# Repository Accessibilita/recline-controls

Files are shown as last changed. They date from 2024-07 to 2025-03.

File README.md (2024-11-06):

# Open Source Wheel Chair Recline Control System
## Hardware project for open source wheel chair recline control electronics

The Recline control system allows the wheel chair user to adjust the recline position of their chair at their leisrure. Its a complete electrical controls system with with safety in mind. The system is split across two piece of electrical hardware design as two separated printed circuit boards. The First board functions as the controller and human machine interface, the second board functions as an intelligent controller for the actuators, solenoids, and air compressor related to controlling the chair recline postion and the chair's pneumatic suspension.The human machine interface board is called the Reline Control board, and the actuator controller is called the Recline Actuator Control board. 

The system is split across two printed circuit boards for a couple of reasons, the signals from the switches and buttons are low voltage signals, running those signals through long wires would cause problems witha accurately reading the position of the rocker switches and buttons due to voltage drop, the LEDs in the 7 segment display have a low forward voltage and need to be close to the driving source for them to work, if the wire is too long voltage drop would prevent the LEDs from turning on, the other reason is the actuators and solenoids are high voltage signals and need to be mounted close to the control board. The Recline Control Board will be mounted on the arm rest of the users's dominant hand, it runs off 24V power and sends commands to the Recline Actuator control board via RS485 serial communication. The Recline Actuator Control board will be mounted in a secure location most likely at the botton of the chair between the chair and it the rolling chassis, it will be fed 24V power and connect to the Recline Control Baord via RS485. 

## Block Diagram of Entire System
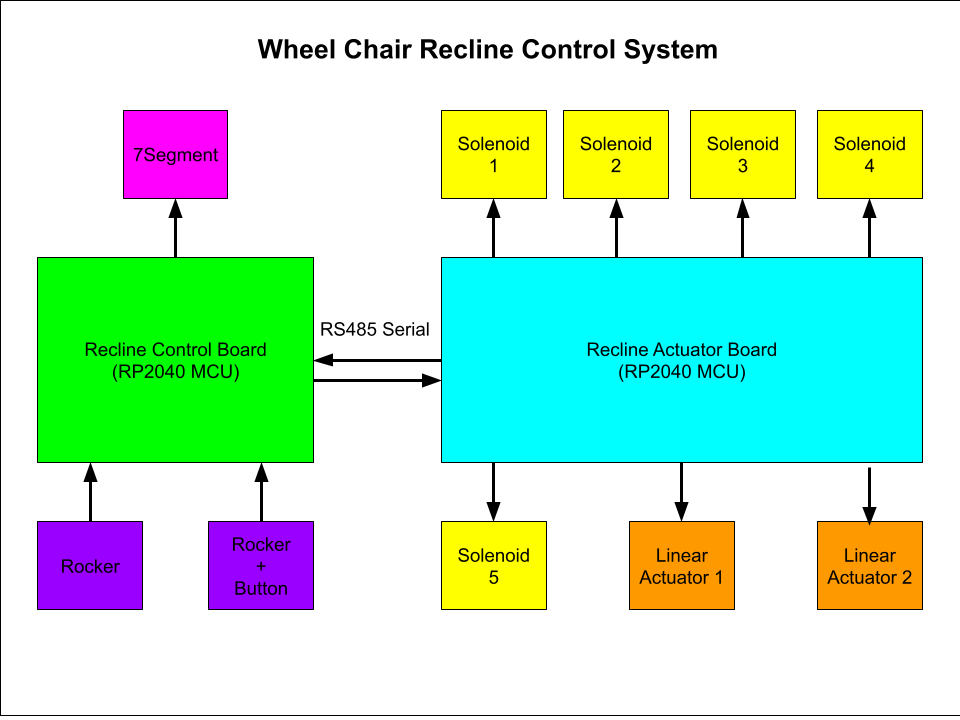
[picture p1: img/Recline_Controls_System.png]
System Diagram


# Board Specs and 3D Renders:

## Recline Control Board 

The other board, called the Recline Control board, functions as the user interface and control center. Here's what it does:

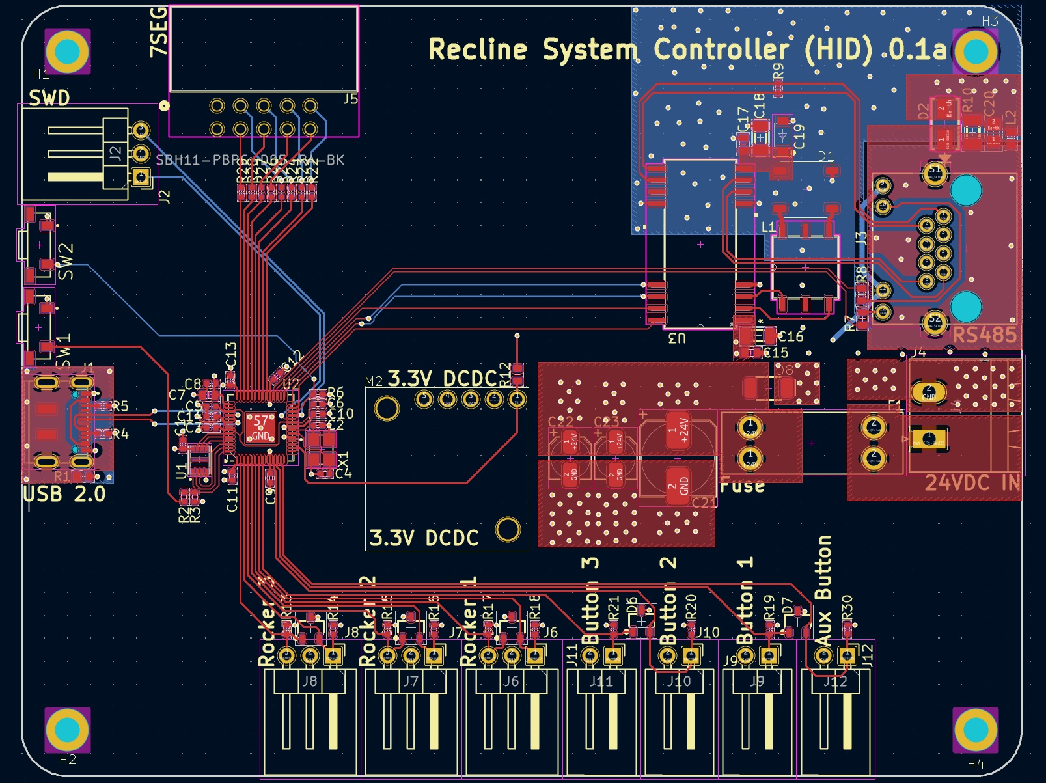
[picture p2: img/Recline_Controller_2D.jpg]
Recline Control Board 2D Render


  Acts as the Human-Machine Interface (HMI): This board is where the user interacts with the system, using buttons and rocker switches to adjust the recline position of the chair.
  Processes Low-Voltage Signals: It handles low-voltage signals from the user input controls, like switches and buttons, to avoid issues with voltage drop.
  Displays Information: Includes a 7-segment display to show information, such as the recline position, which requires low forward voltage and needs to be close to the control board to avoid voltage drops.
  Sends Commands via RS485: It sends user commands to the Recline Actuator Control board through RS485 serial communication, which then controls the actuators and other high-voltage components.
  Mounted for User Access: It’s mounted on the armrest of the user's dominant hand, providing easy access for adjustments.

In essence, the Recline Control board is the user-friendly interface, interpreting user input and communicating these commands to the Recline Actuator Control board via RS485 to execute the recline and suspension adjustments.

### Specs:
- RP2040 Microcontroller
- Pololu DCDC Switching Regulator Modules for 3.3V and 5V Power
- Locking Molex connector for Rocker Switches and Buttons
- RJ45 Connector for RS485 Signals 
- Phoenix Contact high voltage connector for Power Input
- Automotive Blade Fuse Carrier and Crowbar Circuit Protection

### 3D Renders:

Top
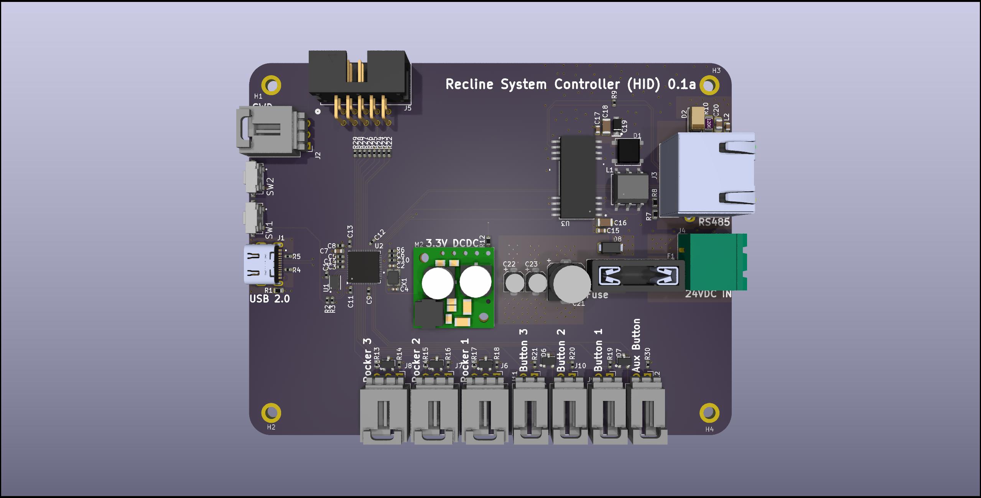
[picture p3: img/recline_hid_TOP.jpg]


Bottom
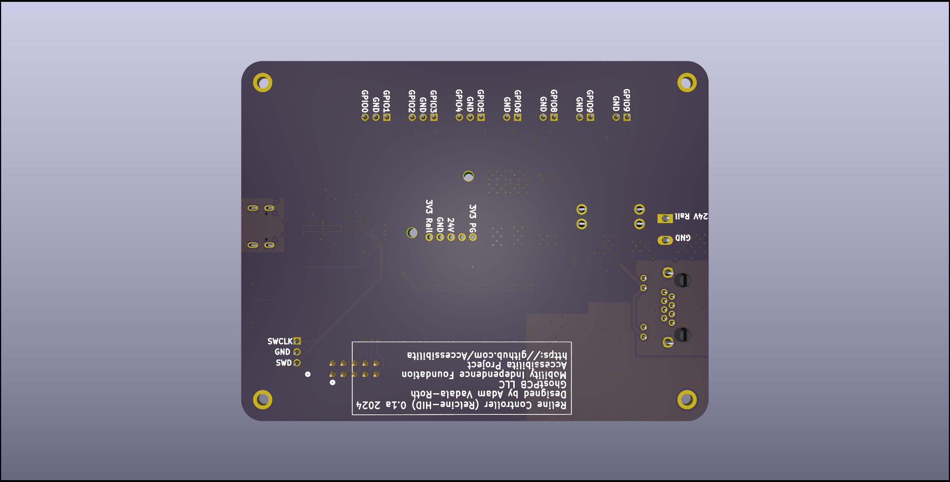
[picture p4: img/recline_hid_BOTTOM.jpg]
Bottom


ISO
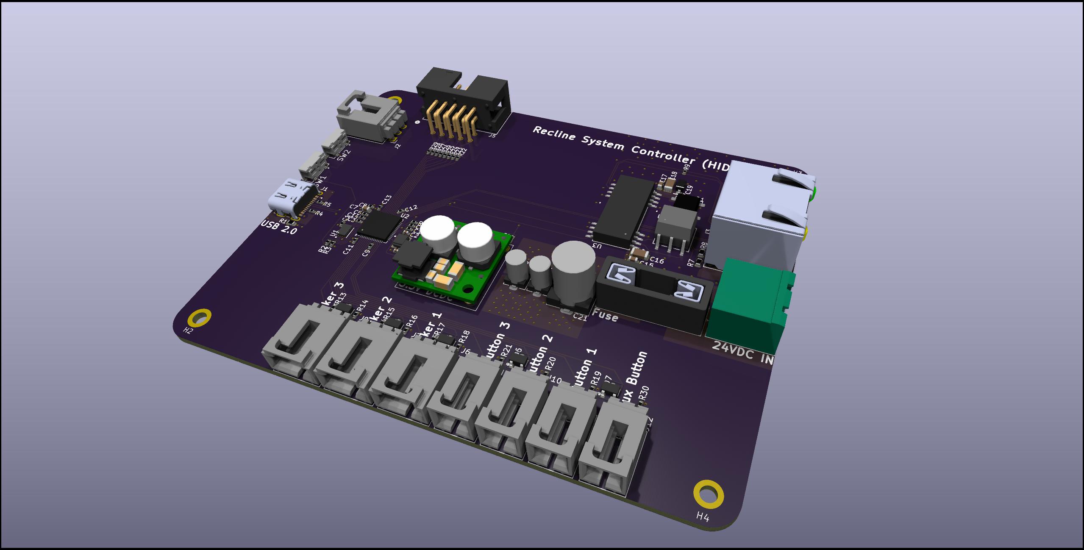
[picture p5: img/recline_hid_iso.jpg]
ISO


Side A
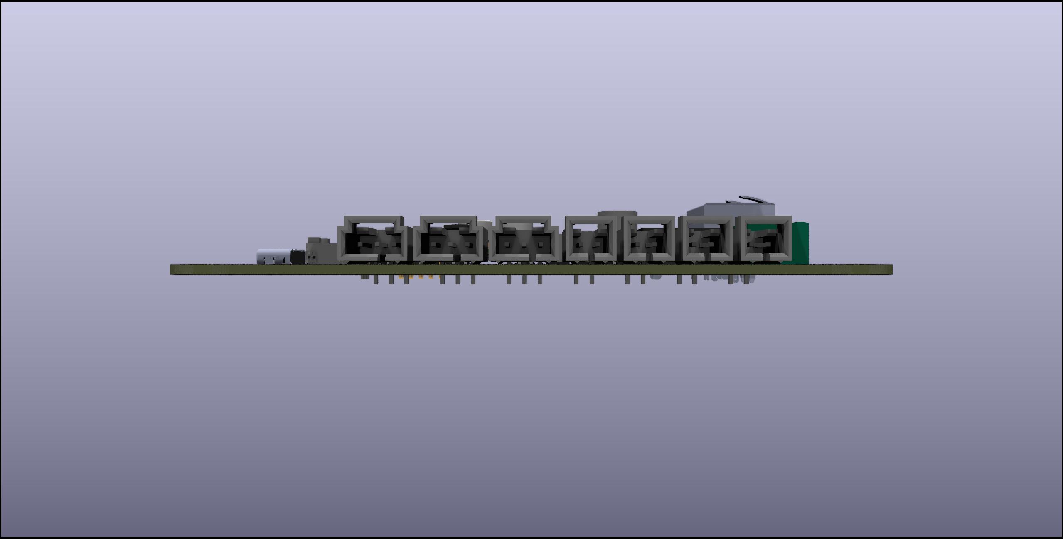
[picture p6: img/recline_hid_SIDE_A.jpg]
Side A


Side B
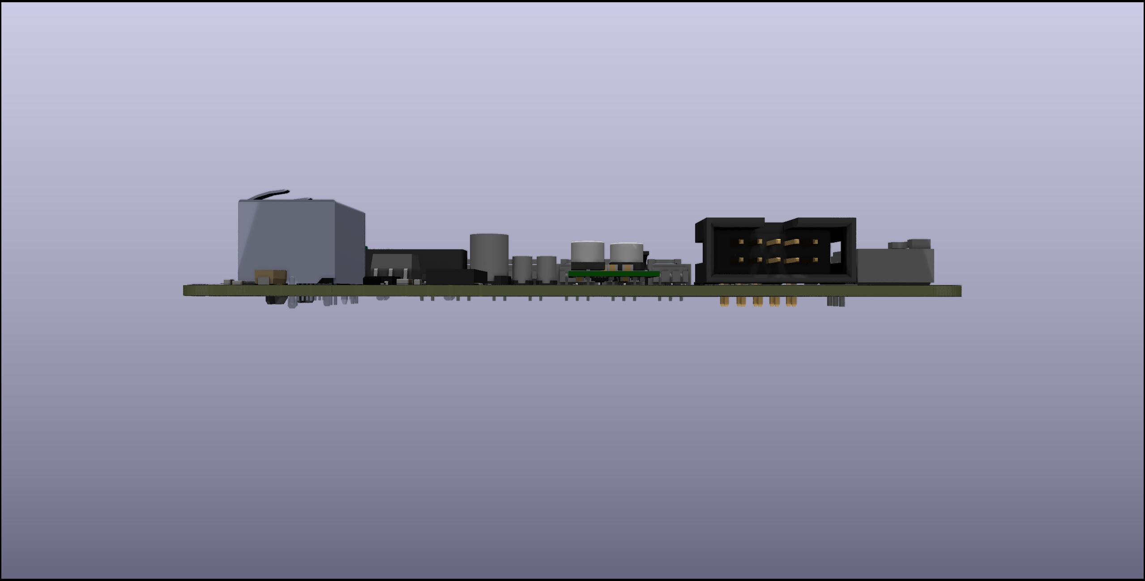
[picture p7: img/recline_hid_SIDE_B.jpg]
Side B


Side C
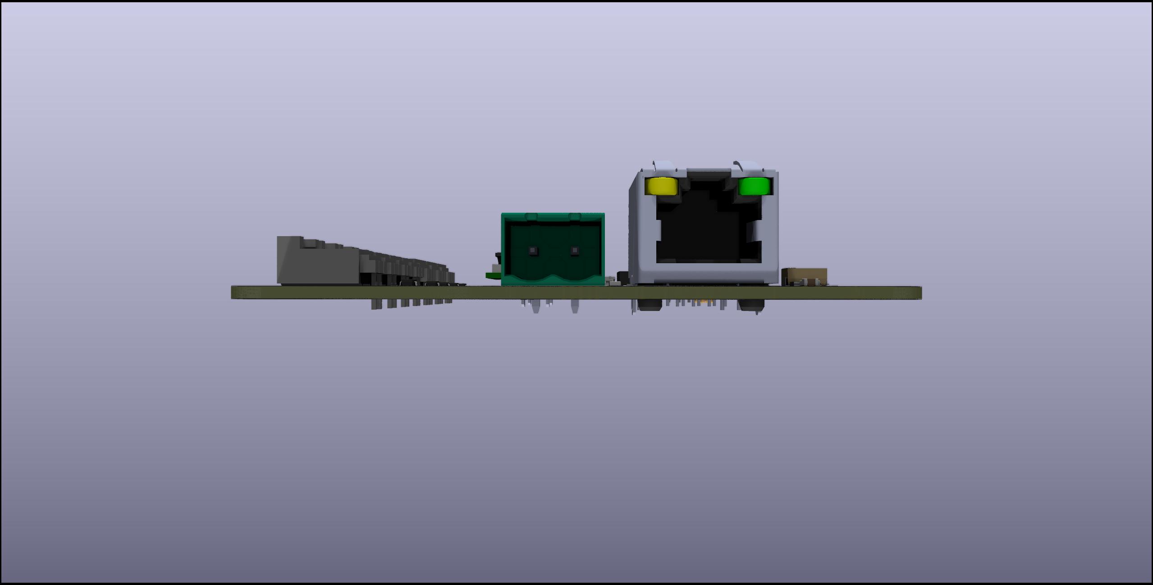
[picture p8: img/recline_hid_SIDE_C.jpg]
Side C


Side D
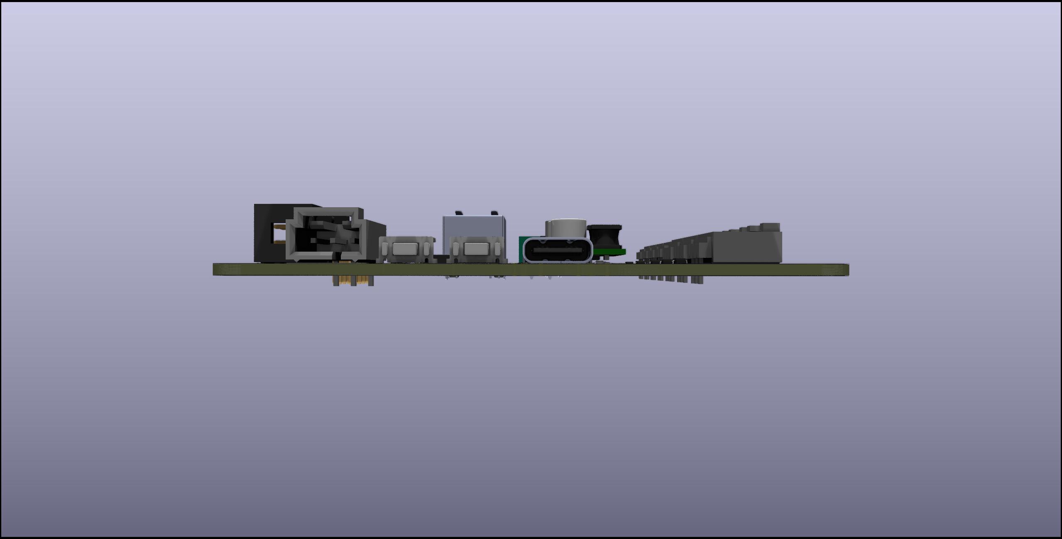
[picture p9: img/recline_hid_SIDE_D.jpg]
Side D


## Recline Actuator Control Board

The Recline Actuator Control board manages the high-voltage signals and controls the mechanical components involved in adjusting the wheelchair's recline position and pneumatic suspension. Specifically, it:

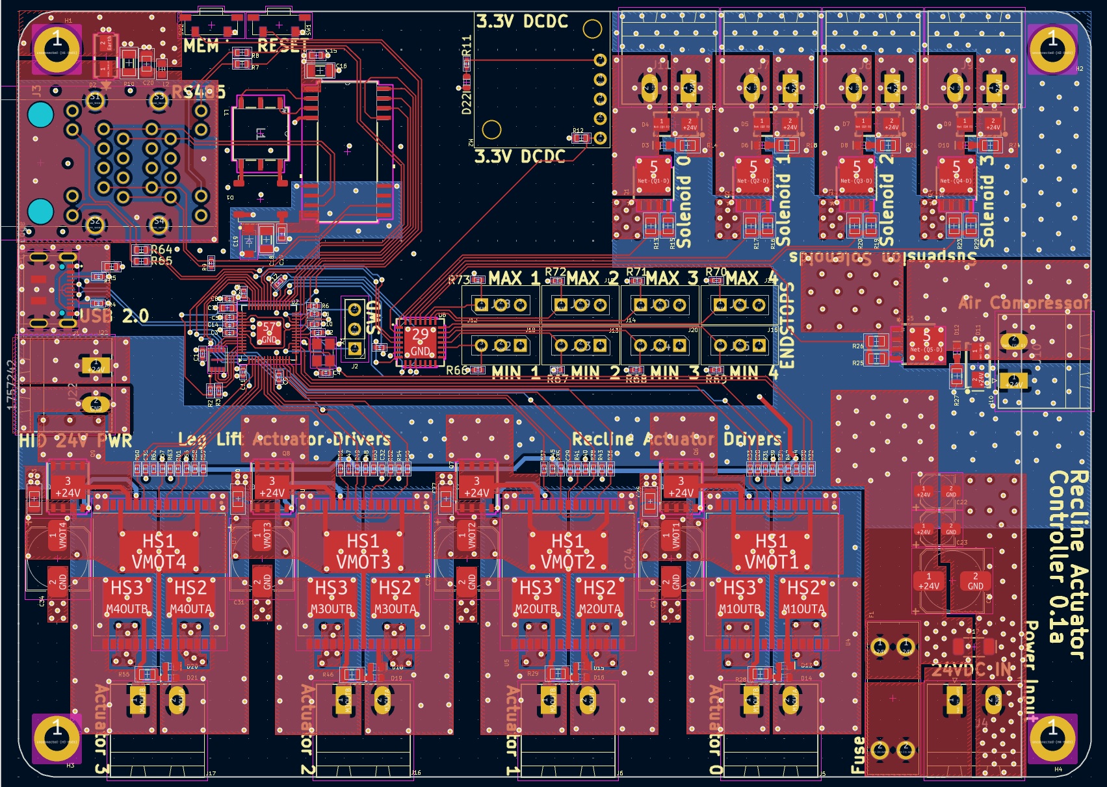
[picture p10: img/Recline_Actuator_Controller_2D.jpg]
Recline Actuator Control Board 2D Render


- Controls Actuators and Solenoids: It interfaces with and controls the actuators and solenoids that adjust the recline position.
- Manages the Air Compressor: It controls the air compressor for the chair's pneumatic suspension.
- Receives Commands via RS485: The board receives commands from the Recline Control board through an RS485 serial communication link.

In summary, this board serves as the power and actuator management hub, ensuring precise, responsive adjustments to the chair's recline and suspension functions based on user commands.

### Specs:
- RP2040 Microcontroller
- Pololu DCDC Switching Regulator Modules for 3.3V and 5V Power
- RJ45 Connector for RS485 Signals 
- Phoenix Contact high voltage connector for Power Input
- Automotive Blade Fuse Carrier and Crowbar Circuit Protection
- Phoenix Contact high voltage connectors for solenoids and DC Motors
- x2 VNH5019 H-Bridges
- 5 MOSFETS for controlling solenoids and air pump

### 3D Renders: 

Top
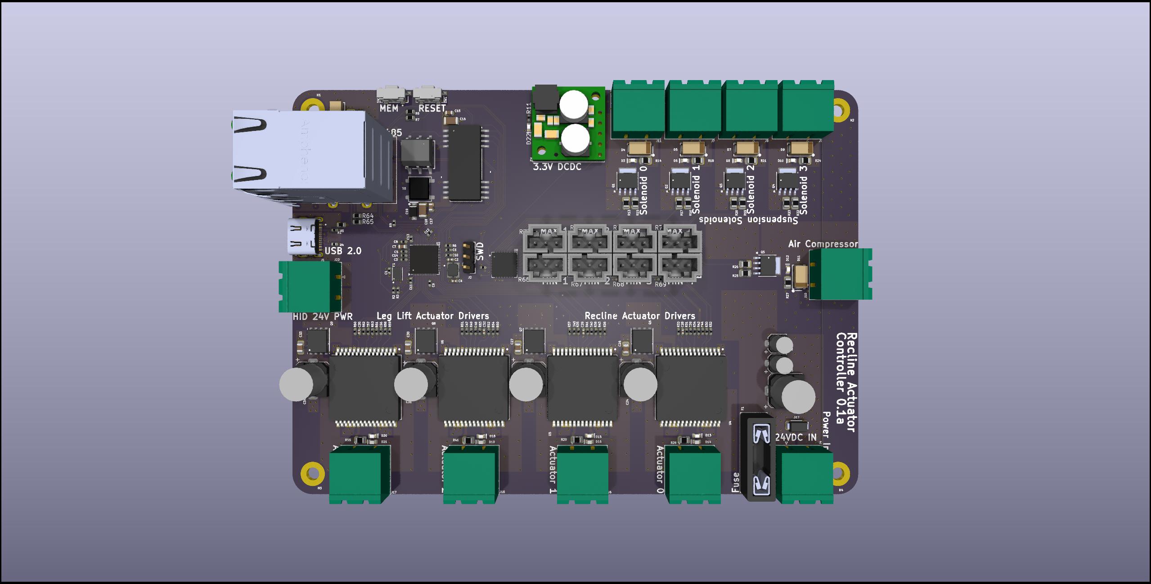
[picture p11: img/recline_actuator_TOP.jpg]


Bottom
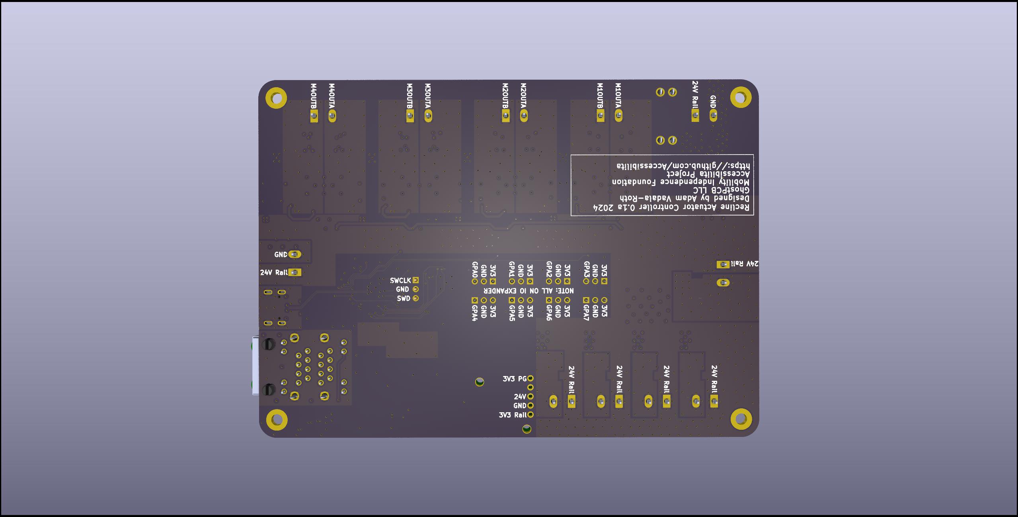
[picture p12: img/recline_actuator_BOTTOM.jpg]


ISO
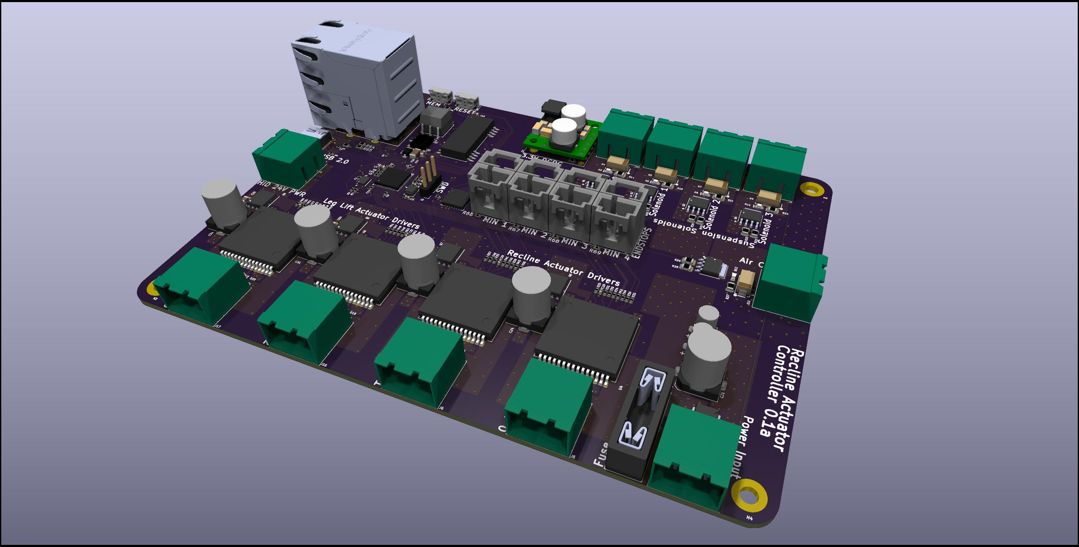
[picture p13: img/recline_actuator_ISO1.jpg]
ISO 1


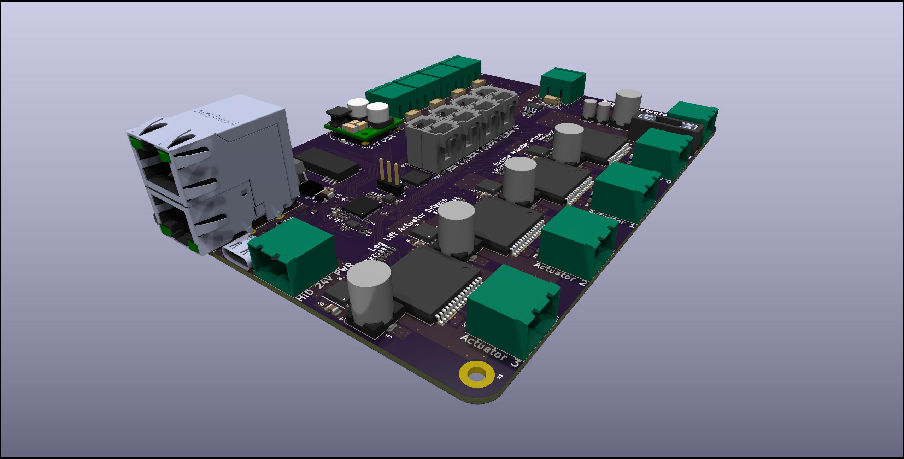
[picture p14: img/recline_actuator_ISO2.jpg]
ISO 2


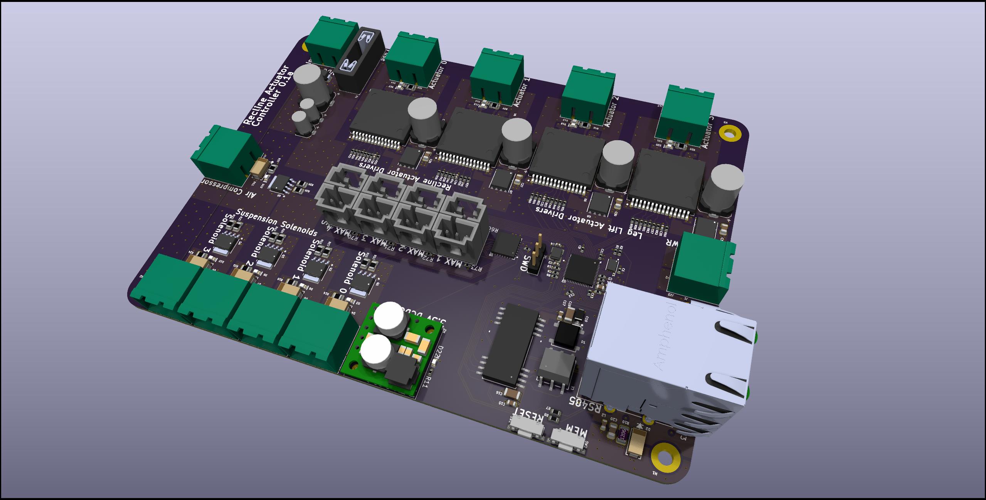
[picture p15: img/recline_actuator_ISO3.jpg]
ISO 3


Side A
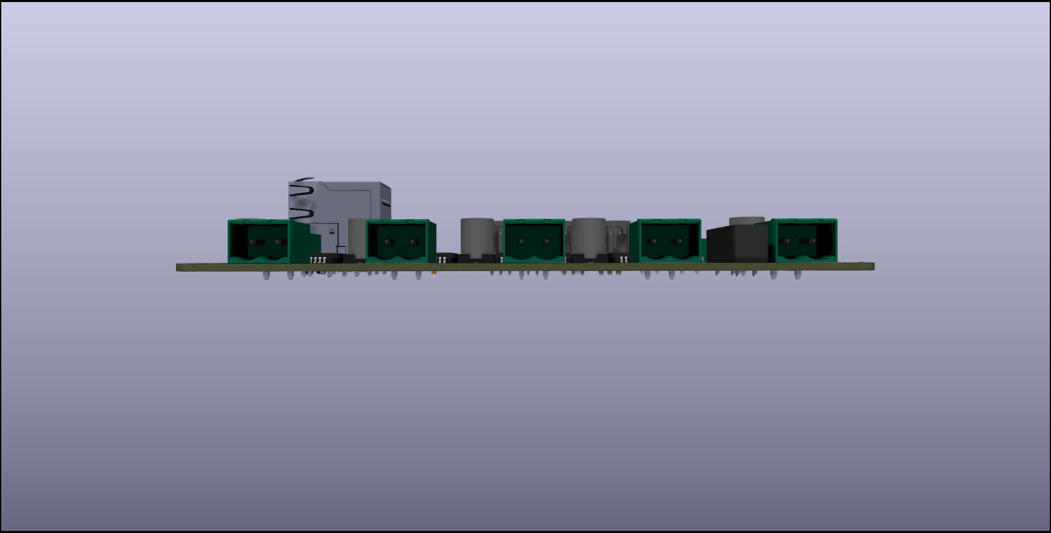
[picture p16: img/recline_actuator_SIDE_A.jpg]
Side A


Side B
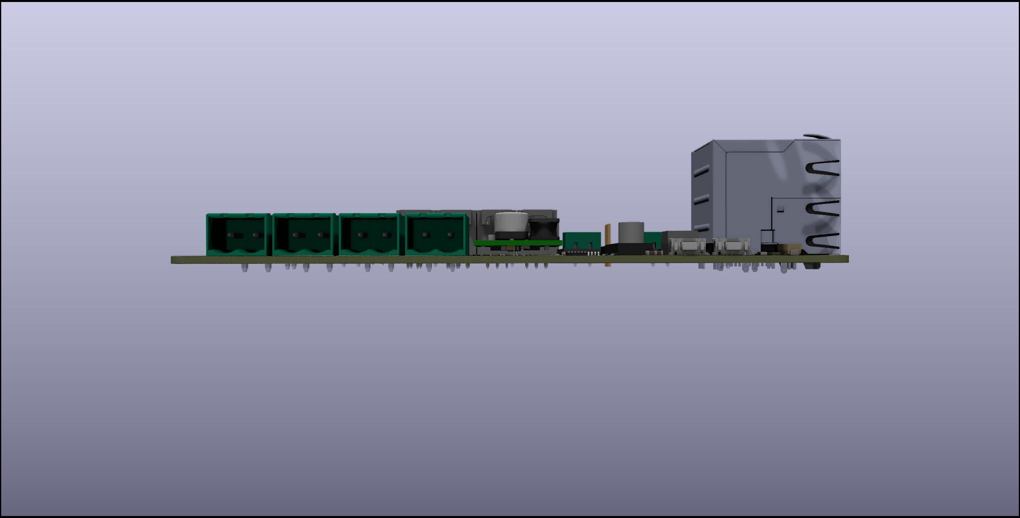
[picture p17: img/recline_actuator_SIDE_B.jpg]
Side B


Side C
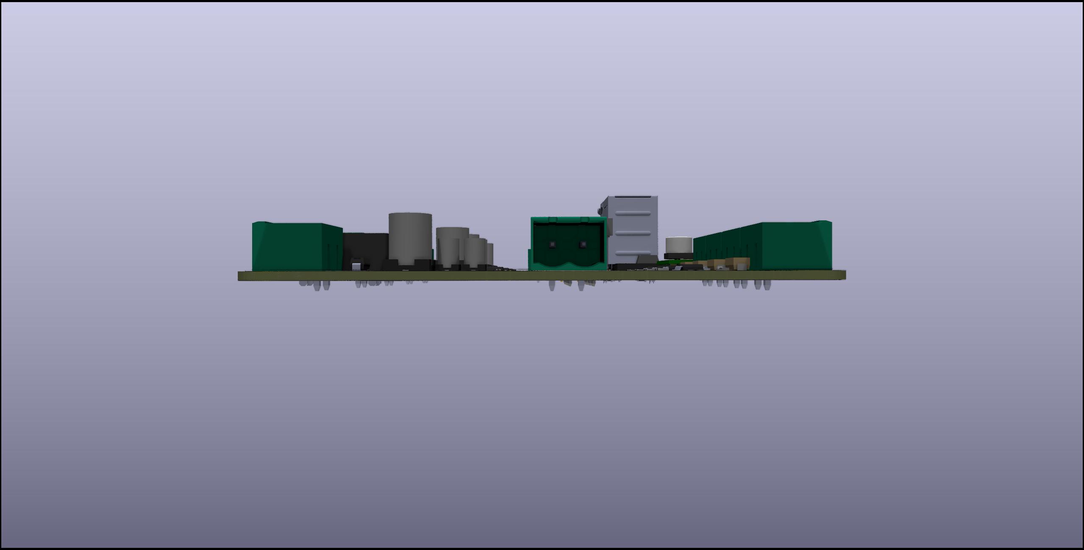
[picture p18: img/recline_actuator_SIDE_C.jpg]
Side C


Side D
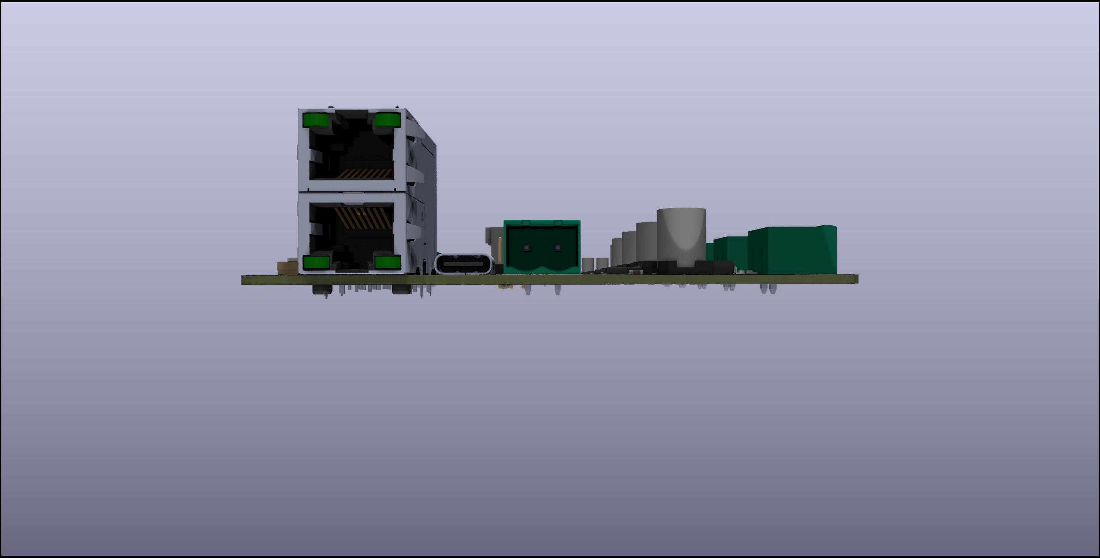
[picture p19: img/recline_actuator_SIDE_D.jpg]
Side D


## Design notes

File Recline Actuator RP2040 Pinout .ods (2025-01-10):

RP2040 GPIO Pin | Function
GPIO0 | M4INB, Signal for Actuator 4 H-Bridge, Configured as Output
GPIO1 | M4PWM, PWM Output for Actuator 4 H-Bridge, Configured as Output
GPIO2 | M4ENA/B, Signal for Actuator 4 H-Bridge, Configured as Output
GPIO3 | M4INA, SIgnal for Actuator 4 H-Bridge, Configured as Output
GPIO4 | M3INB, Signal for Actuator 3 H-Bridge, Configured as Output
GPIO5 | M3ENA/B, Signal for Actuator 3 H-Bridge, Configured as Output
GPIO6 | M3PWM, PWM Output for Actuator 3 H-Bridge
GPIO7 | M3INA, Signal for Actuator 3 H-Bridge, Configured as Output
GPIO8 | M2INB, Signal for Actuator 2 H-Bridge, Configured as Output
GPIO9 | M2ENA/B, Signal for Actuator 2 H-Bridge, Configured as Output
GPIO10 | M2PWM, PWM Output for Actuator 2 H-Bridge
GPIO11 | M2INA, Signal for Actuator 2 H-Bridge , Configured as Output
GPIO12 | M1INB, Signal for Actuator 1 H-Bridge , Configured as Output
GPIO13 | M1PWM, PWM Output for Actuator 1 H-Bridge
GPIO14 | M1ENA/B, Signal for Actuator 1 H-Bridge, Configured as Output
GPIO15 | M1INA, Signal for Actuator 1 H-Bridge , Configured as Output
GPIO16 | UART TXD
GPIO17 | UART RXD
GPIO18 | UART TX EN
GPIO19 | UART RX EN
GPIO20 | SPI0 RX
GPIO21 | SPI0 CS
GPIO22 | SPI0 SCK
GPIO23 | SPI0 TX
GPIO24 | Output for UART RX LED
GPIO25 | OUtput for UART TX LED
GPIO26 | Analog Input for Actuator 1 H-Bridge Current Sensing
GPIO27 | Analog Input for Actuator 2 H-Bridge Current Sensing
GPIO28 | Analog Input for Actuator 3 H-Bridge Current Sensing
GPIO29 | Analog Input for Actuator 4 H-Bridge Current Sensing
MCP23S17T-E/ML | Function
GPA0 | Enstop 1 Minimum, Configured as Input
GPA1 | Enstop 2 Minimum, Configured as Input
GPA2 | Enstop 3 Minimum, Configured as Input
GPA3 | Enstop 4 Minimum , Configured as Input
GPA4 | Enstop 1 Maxmimum, Configured as Input
GPA5 | Enstop 2 Maxmimum , Configured as Input
GPA6 | Enstop 3 Maxmimum , Configured as Input
GPA7 | Enstop 4 Maxmimum , Configured as Input
GPB0 | Air Compressor MOSFET Output
GPB1 | Solenoid 3 MOSFET Output
GPB2 | Solenoid 2 MOSFET Output
GPB3 | Solenoid 1 MOSFET Output
GPB4 | Solenoid 0 MOSFET Output
GPB5 | 3.3V DCDC Regulator Power Good, Input
GPB6 | RS485 TX LED 2, Output
GPB7 | RS485 RX LED 2, Output

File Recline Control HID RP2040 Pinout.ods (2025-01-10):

RP2040 GPIO Pin | Function
GPIO0 | Input for Rocker Switch
GPIO1 | Input for Rocker Switch
GPIO2 | Input for Rocker Switch
GPIO3 | Input for Rocker Switch
GPIO4 | Input for Rocker Switch
GPIO5 | Input for Rocker Switch
GPIO6 | Input for Button
GPIO8 | Input for Button
GPIO9 | Input for Button
GPIO10 | Input for Button
GPIO13 | Input for Power Good Signal From DCDC Regulator
GPIO16 | UART TXD
GPIO17 | UART RXD
GPIO18 | UART TX EN
GPIO19 | UART RX EN
GPIO20 | Output for UART RX LED
GPIO21 | OUtput for UART TX LED
GPIO22 | Output for 7 Segment Display LED, Segment 0
GPIO23 | Output for 7 Segment Display LED, Segment 1
GPIO24 | Output for 7 Segment Display LED, Segment 2
GPIO25 | Output for 7 Segment Display LED, Segment 3
GPIO26 | Output for 7 Segment Display LED, Segment 4
GPIO27 | Output for 7 Segment Display LED, Segment 5
GPIO28 | Output for 7 Segment Display LED, Segment 6
GPIO29 | Output for 7 Segment Display LED, Segment 7

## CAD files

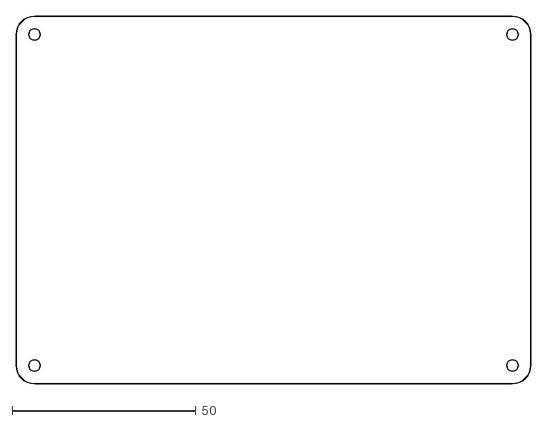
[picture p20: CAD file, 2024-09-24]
PCB/recline-actuator-controller/Actator_Board_Shape.dxf
140.0 x 100.0

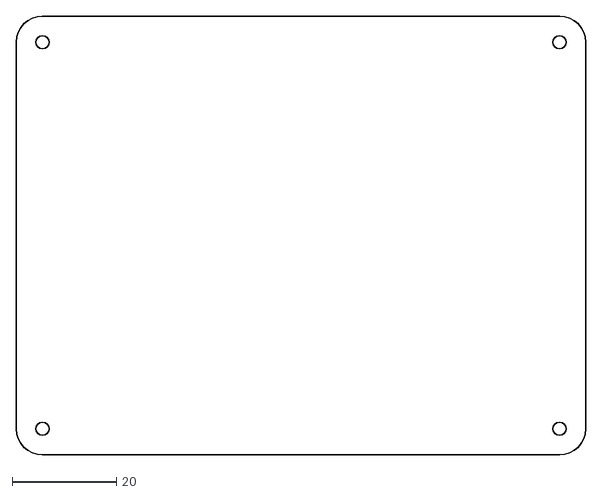
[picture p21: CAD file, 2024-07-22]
PCB/recline-controls/Recline_Control_Board_1590BBBK_Shape.dxf
109.0 x 84.0

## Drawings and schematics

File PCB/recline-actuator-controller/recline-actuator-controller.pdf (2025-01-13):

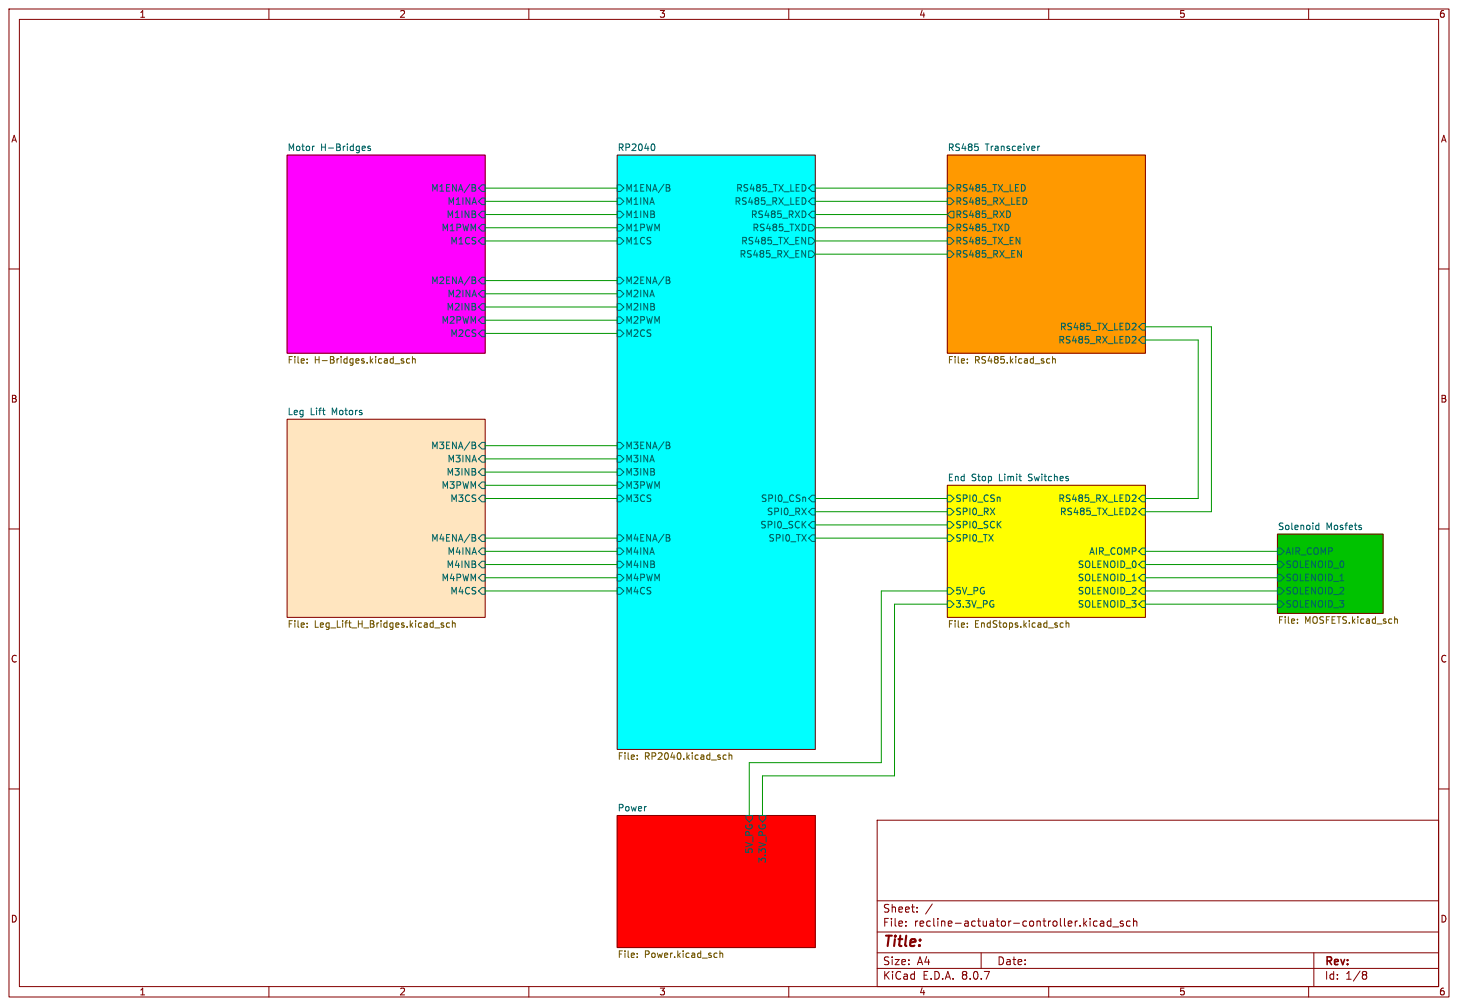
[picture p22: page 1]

Leg Lift Motors File: Leg_Lift_H_Bridges.kicad_sch

Id: 1/8 Title: File: recline-actuator-controller.kicad_sch Sheet: /

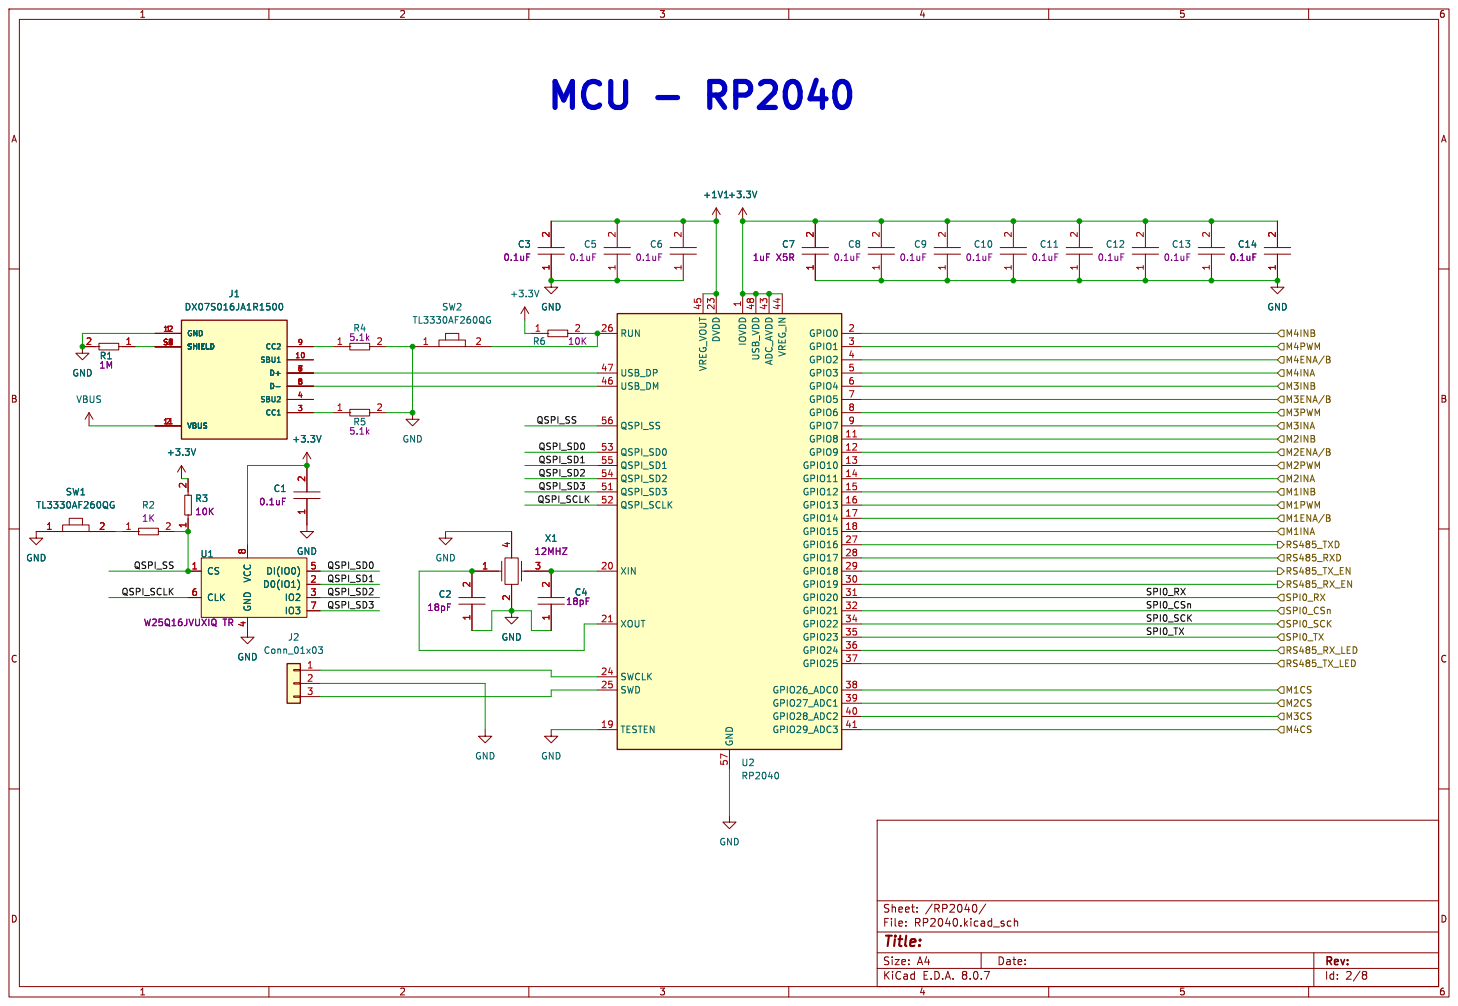
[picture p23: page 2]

1 GPIO8 11 GPIO9 12 GPIO10 13 GPIO11 14 GPIO12 15 GPIO13 16 GPIO14 17 GPIO15 18 TESTEN 19 GPIO0 2 XIN 20 XOUT 21 DVDD 23 SWCLK 24 SWD 25 RUN 26 GPIO16 27 GPIO17 28 GPIO18 29 GPIO1 3 GPIO19 30 GPIO20 31 GPIO21 32 GPIO22 34 GPIO23 35 GPIO24 36 GPIO25 37 GPIO26_ADC0 38 GPIO27_ADC1 39 GPIO2 4 GPIO28_ADC2 40 GPIO29_ADC3 41 ADC_AVDD 43 VREG_IN 44 VREG_VOUT 45 USB_DM 46 USB_DP 47 USB_VDD 48 GPIO3 5 QSPI_SD3 51 QSPI_SCLK 52 QSPI_SD0 53 QSPI_SD2 54 QSPI_SD1 55 QSPI_SS 56 GND 57 GPIO4 6 GPIO5 7 GPIO6 8 GPIO7 9 U2 RP2040 GND GND

Id: 2/8 Title: File: RP2040.kicad_sch Sheet: /RP2040/ GND

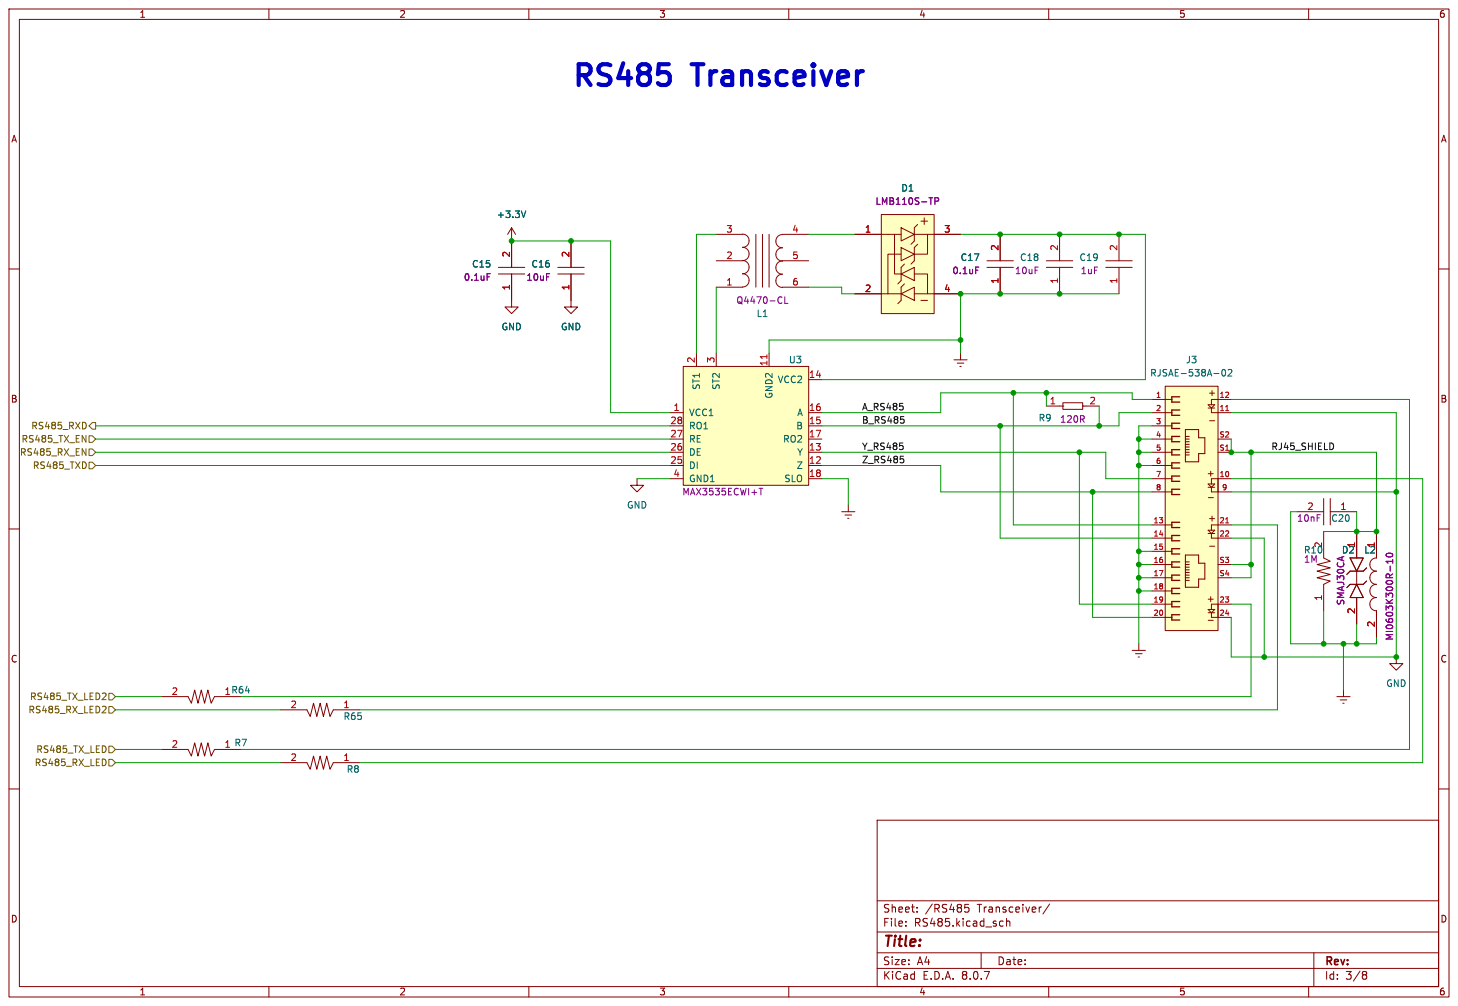
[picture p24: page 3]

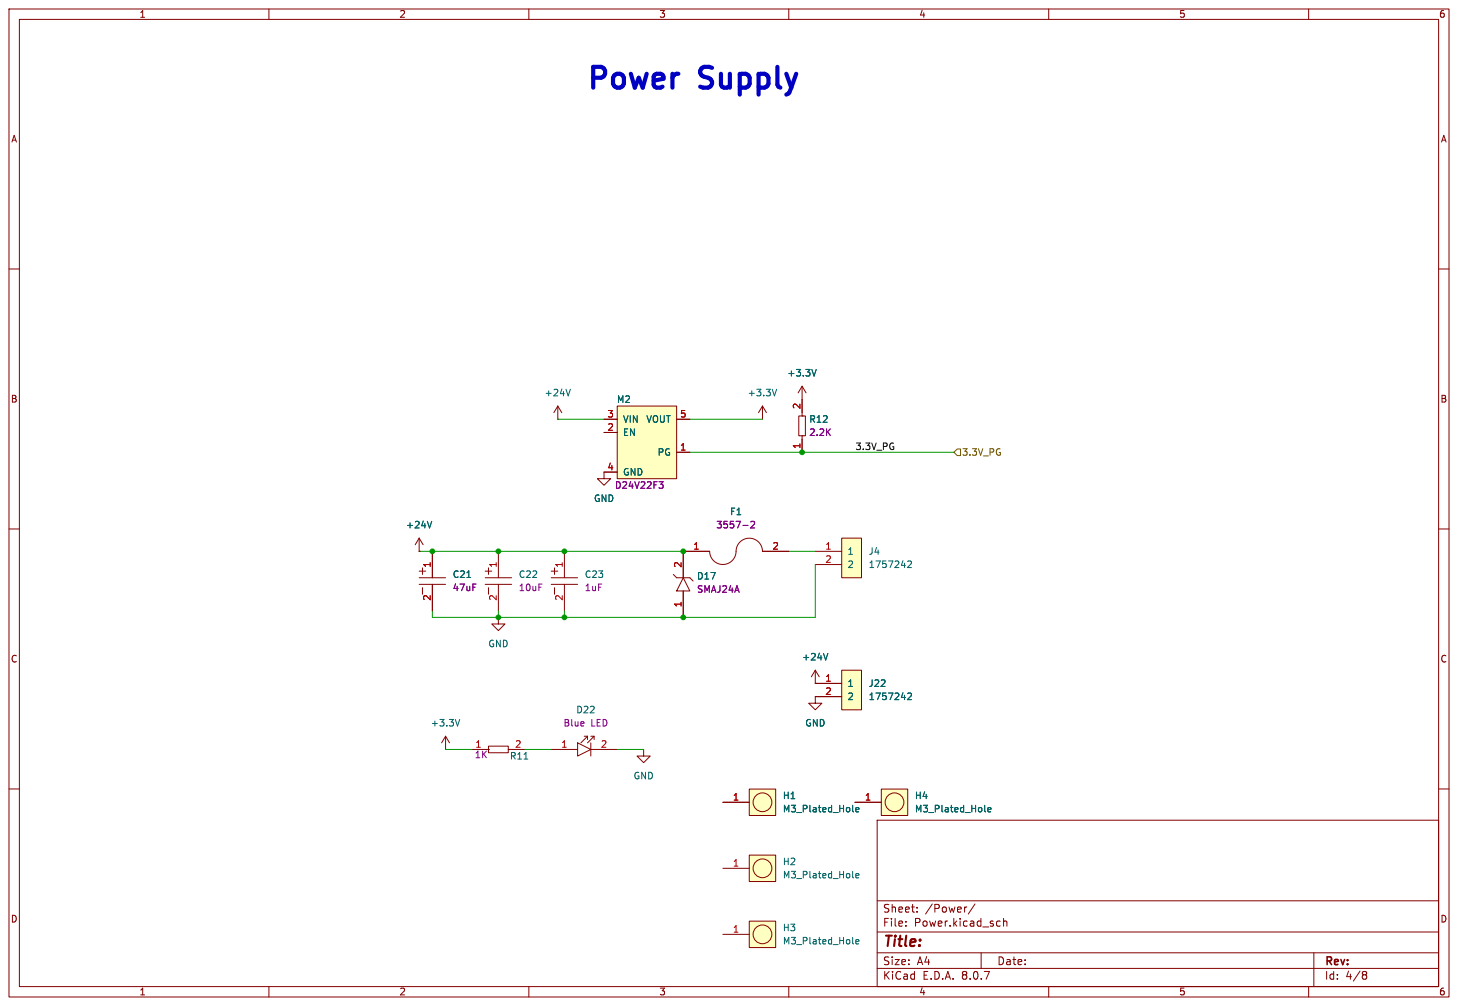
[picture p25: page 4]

Id: 4/8 Title: File: Power.kicad_sch Sheet: /Power/

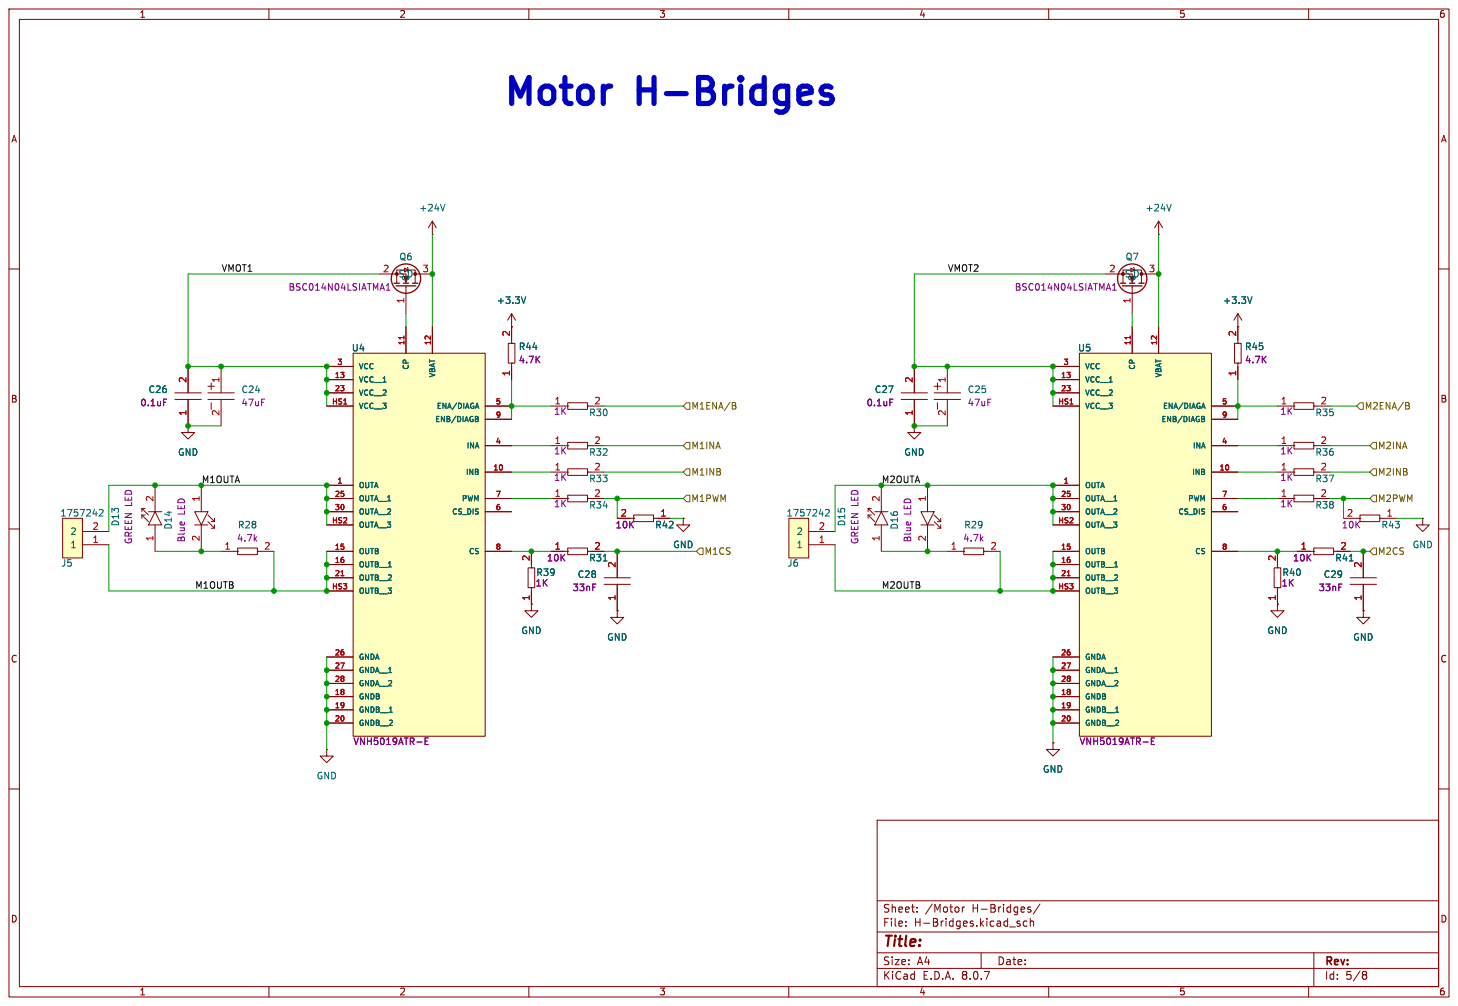
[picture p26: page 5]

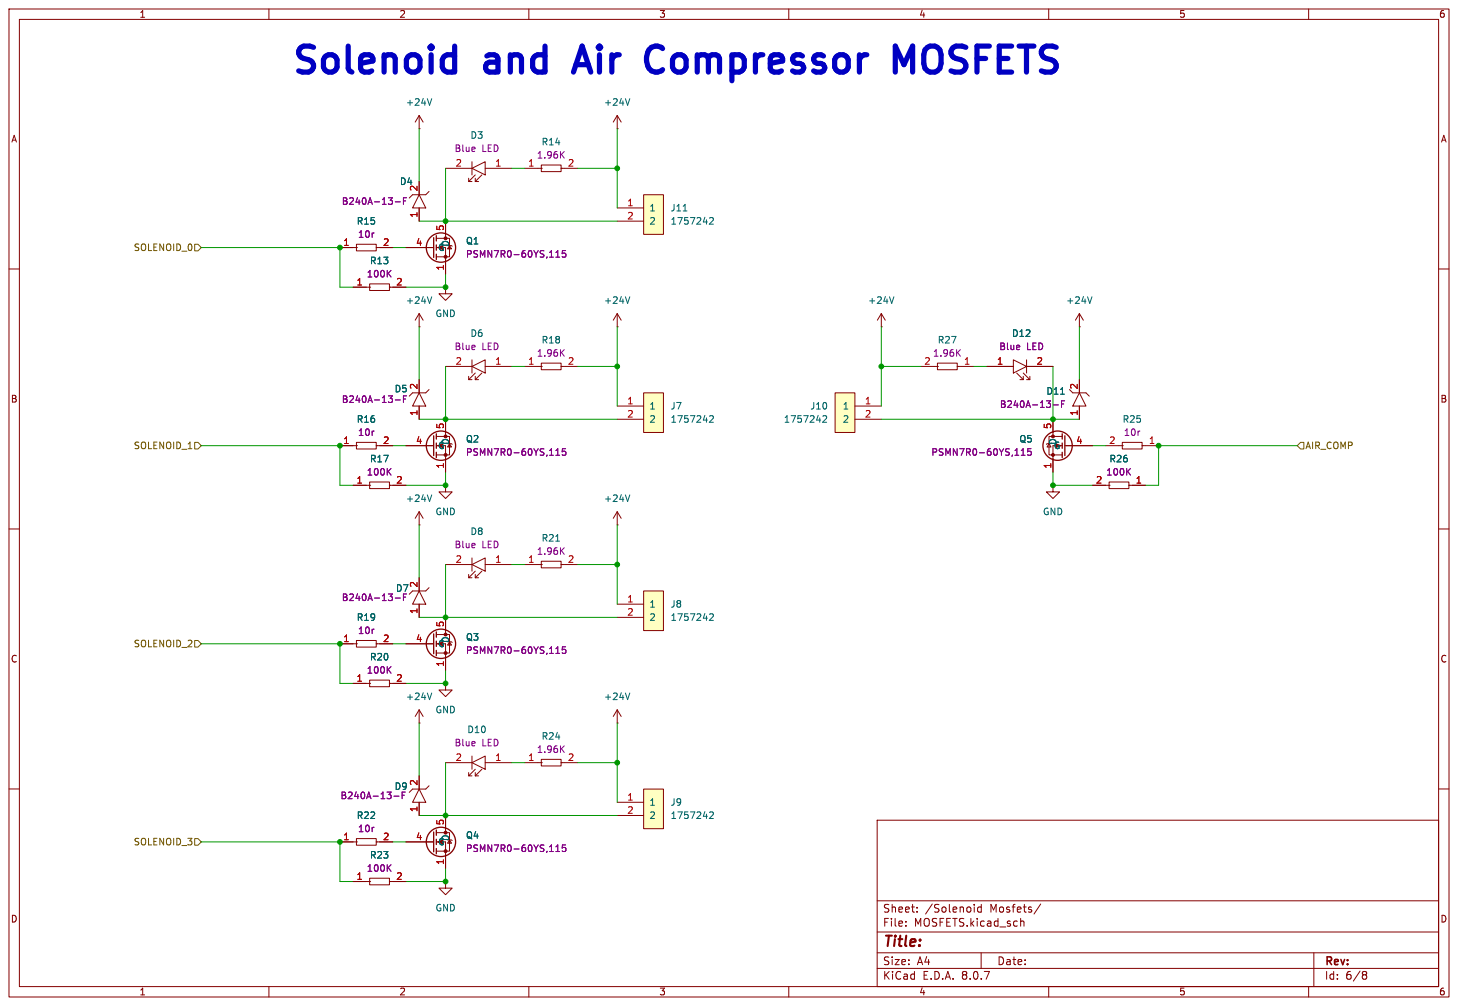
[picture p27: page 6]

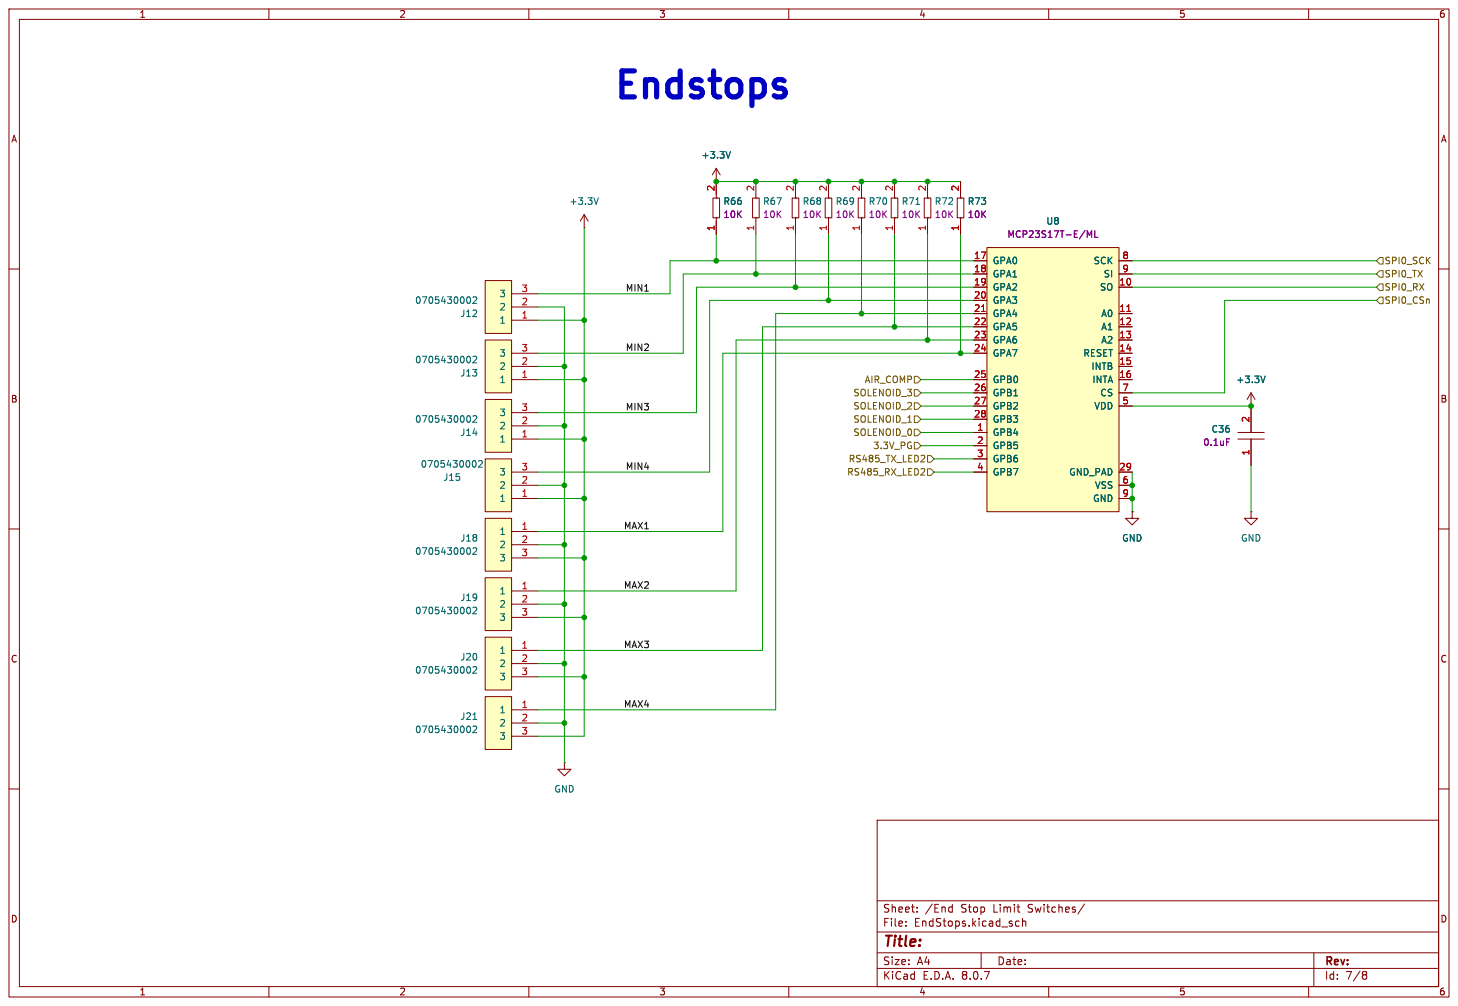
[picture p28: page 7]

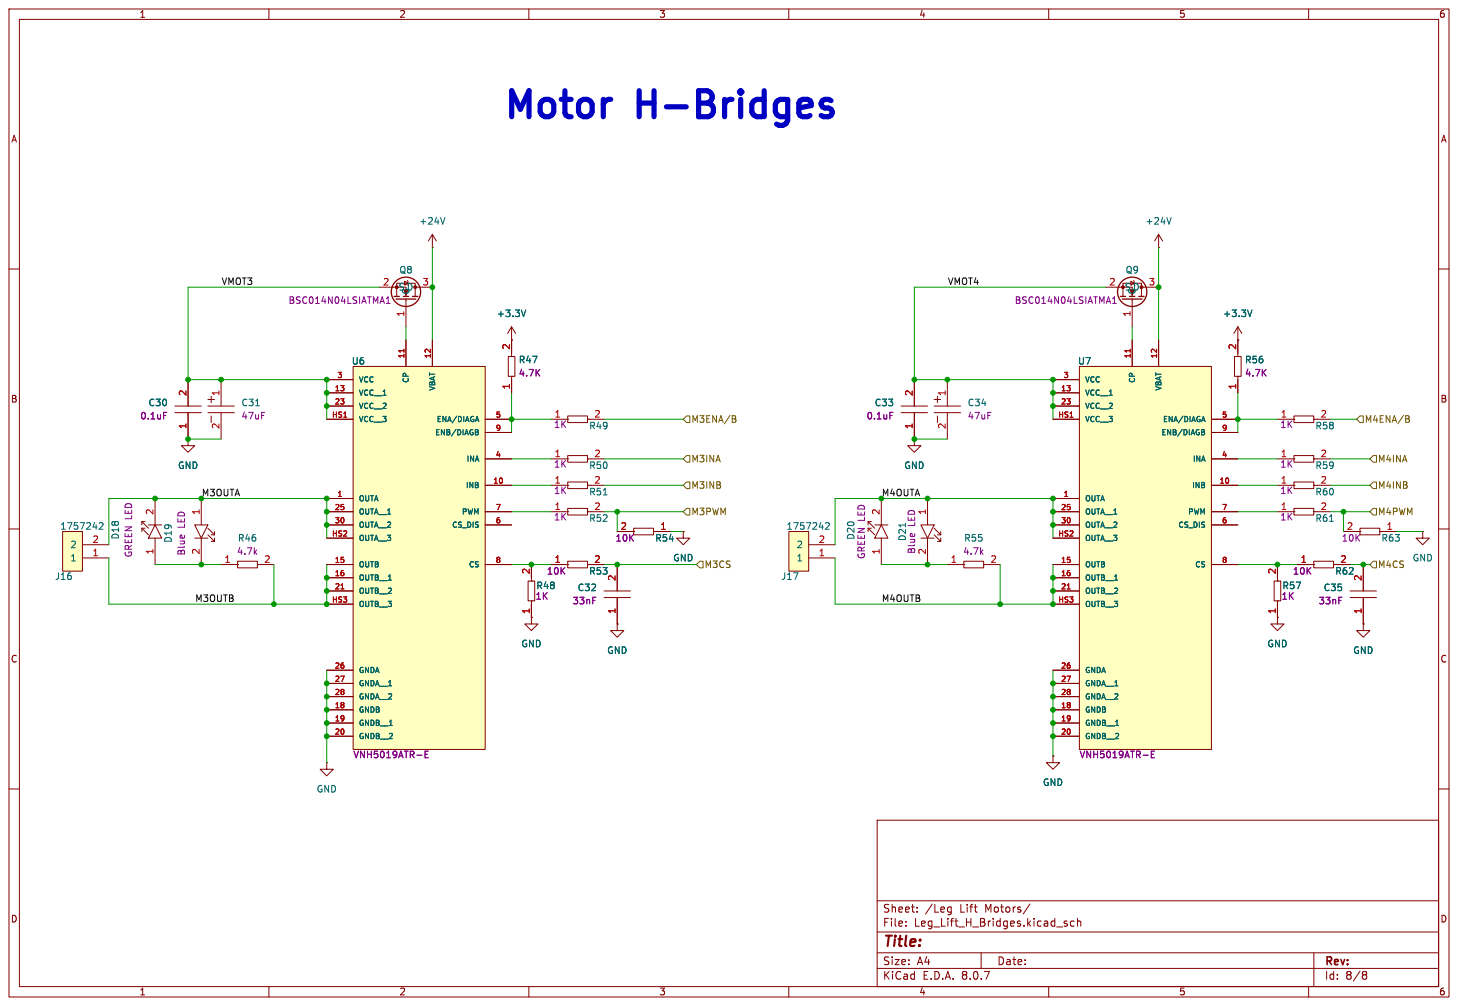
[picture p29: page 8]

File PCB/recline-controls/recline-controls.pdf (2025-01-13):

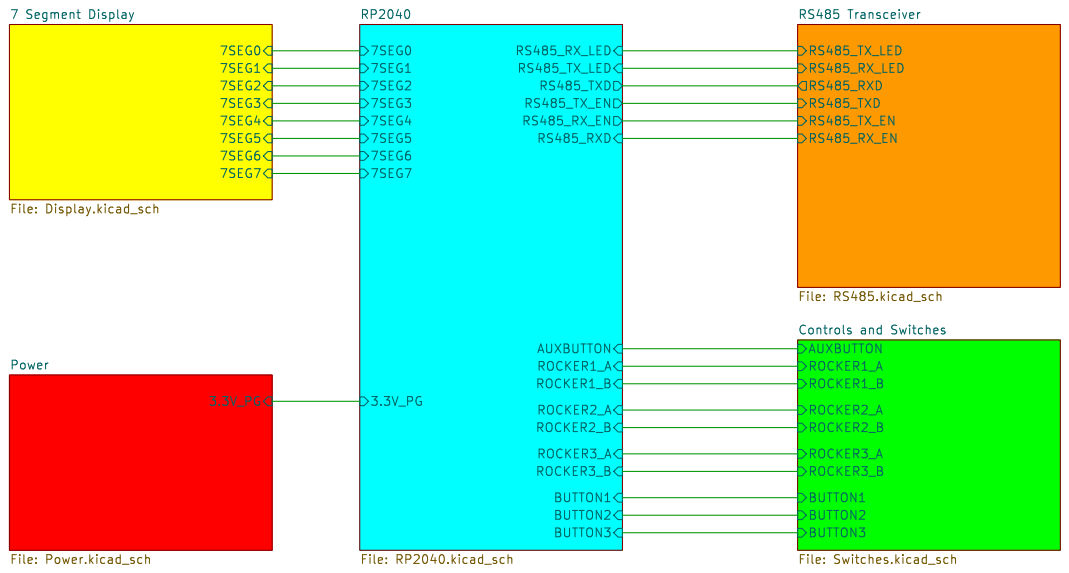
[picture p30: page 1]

7 Segment Display File: Display.kicad_sch

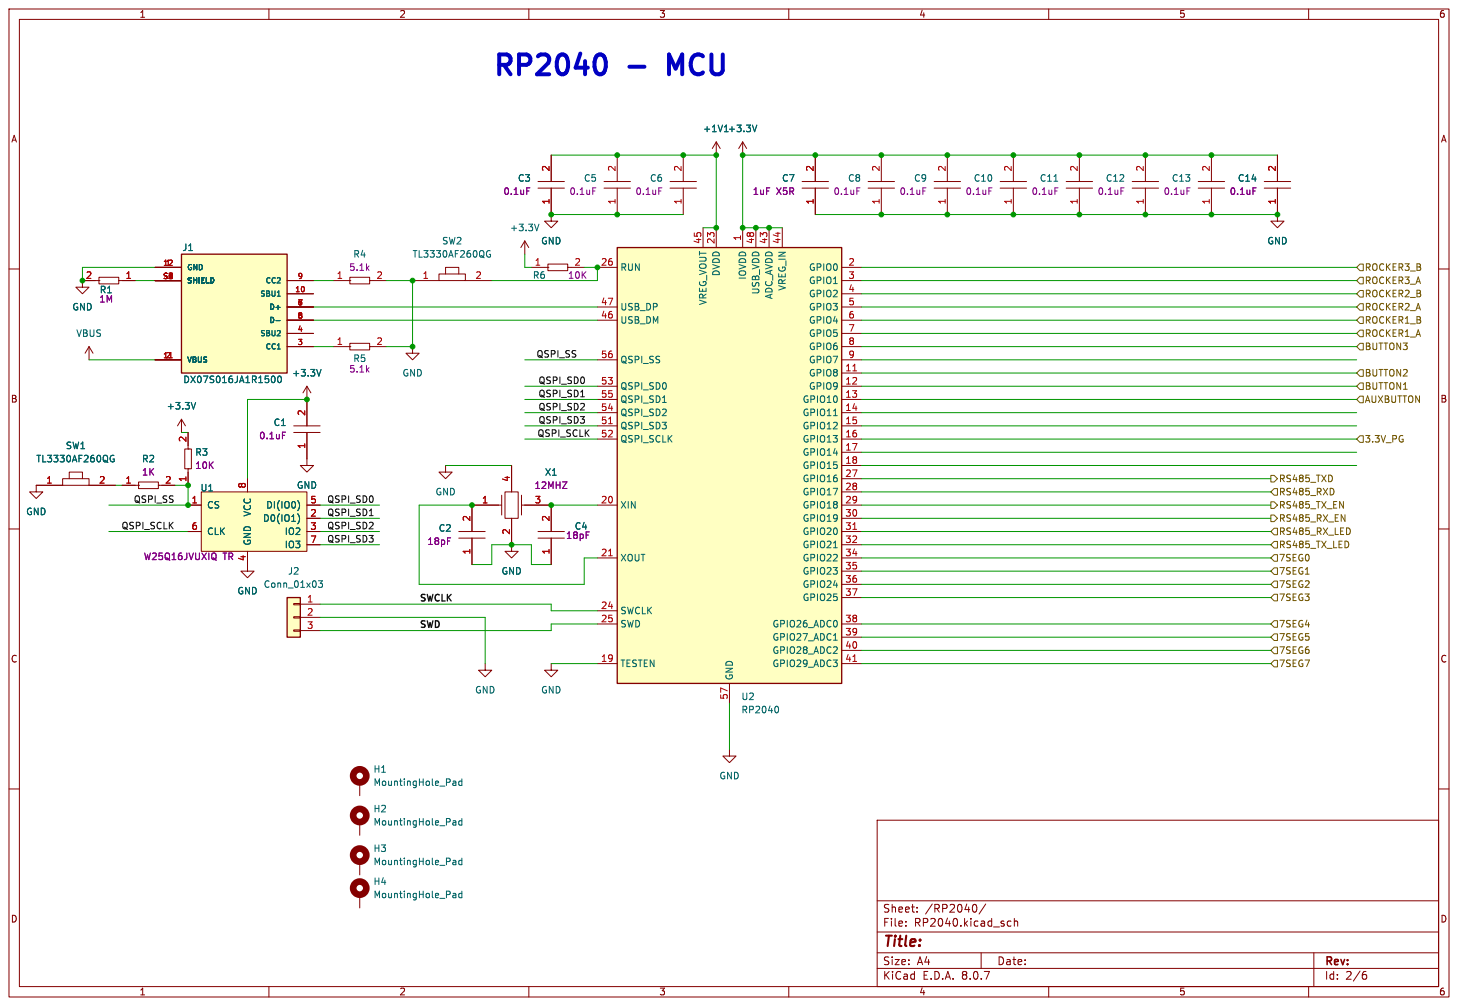
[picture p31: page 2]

1 GPIO8 11 GPIO9 12 GPIO10 13 GPIO11 14 GPIO12 15 GPIO13 16 GPIO14 17 GPIO15 18 TESTEN 19 GPIO0 2 XIN 20 XOUT 21 DVDD 23 SWCLK 24 SWD 25 RUN 26 GPIO16 27 GPIO17 28 GPIO18 29 GPIO1 3 GPIO19 30 GPIO20 31 GPIO21 32 GPIO22 34 GPIO23 35 GPIO24 36 GPIO25 37 GPIO26_ADC0 38 GPIO27_ADC1 39 GPIO2 4 GPIO28_ADC2 40 GPIO29_ADC3 41 ADC_AVDD 43 VREG_IN 44 VREG_VOUT 45 USB_DM 46 USB_DP 47 USB_VDD 48 GPIO3 5 QSPI_SD3 51 QSPI_SCLK 52 QSPI_SD0 53 QSPI_SD2 54 QSPI_SD1 55 QSPI_SS 56 GND 57 GPIO4 6 GPIO5 7 GPIO6 8 GPIO7 9 U2 RP2040

Id: 2/6 Title: File: RP2040.kicad_sch Sheet: /RP2040/

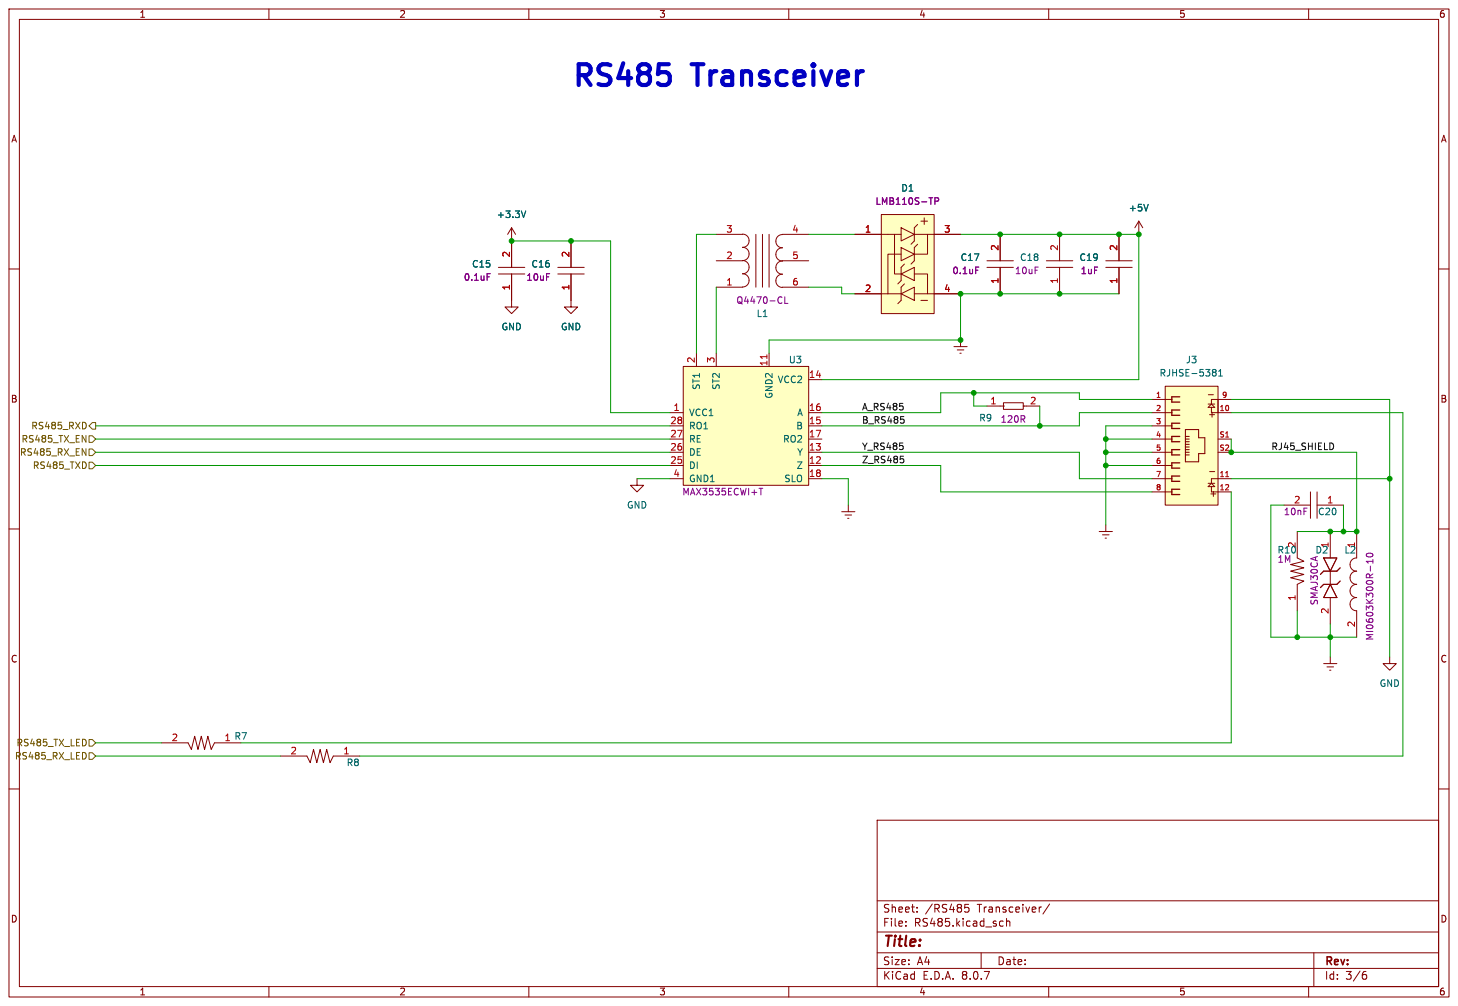
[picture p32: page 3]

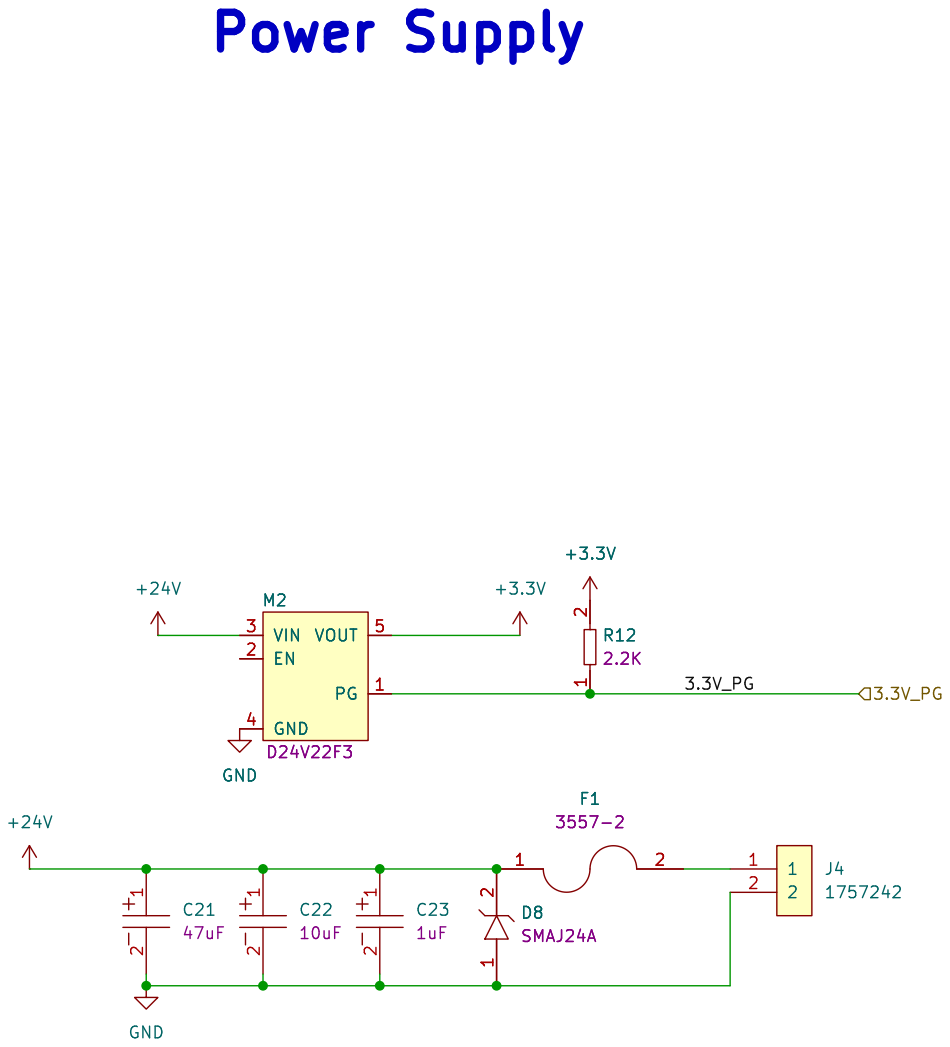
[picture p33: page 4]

1 2 +3.3V M2D24V22F3PG 1 EN 2 VIN 3 GND 4 VOUT 5 GND

Id: 4/6 Title: File: Power.kicad_sch Sheet: /Power/



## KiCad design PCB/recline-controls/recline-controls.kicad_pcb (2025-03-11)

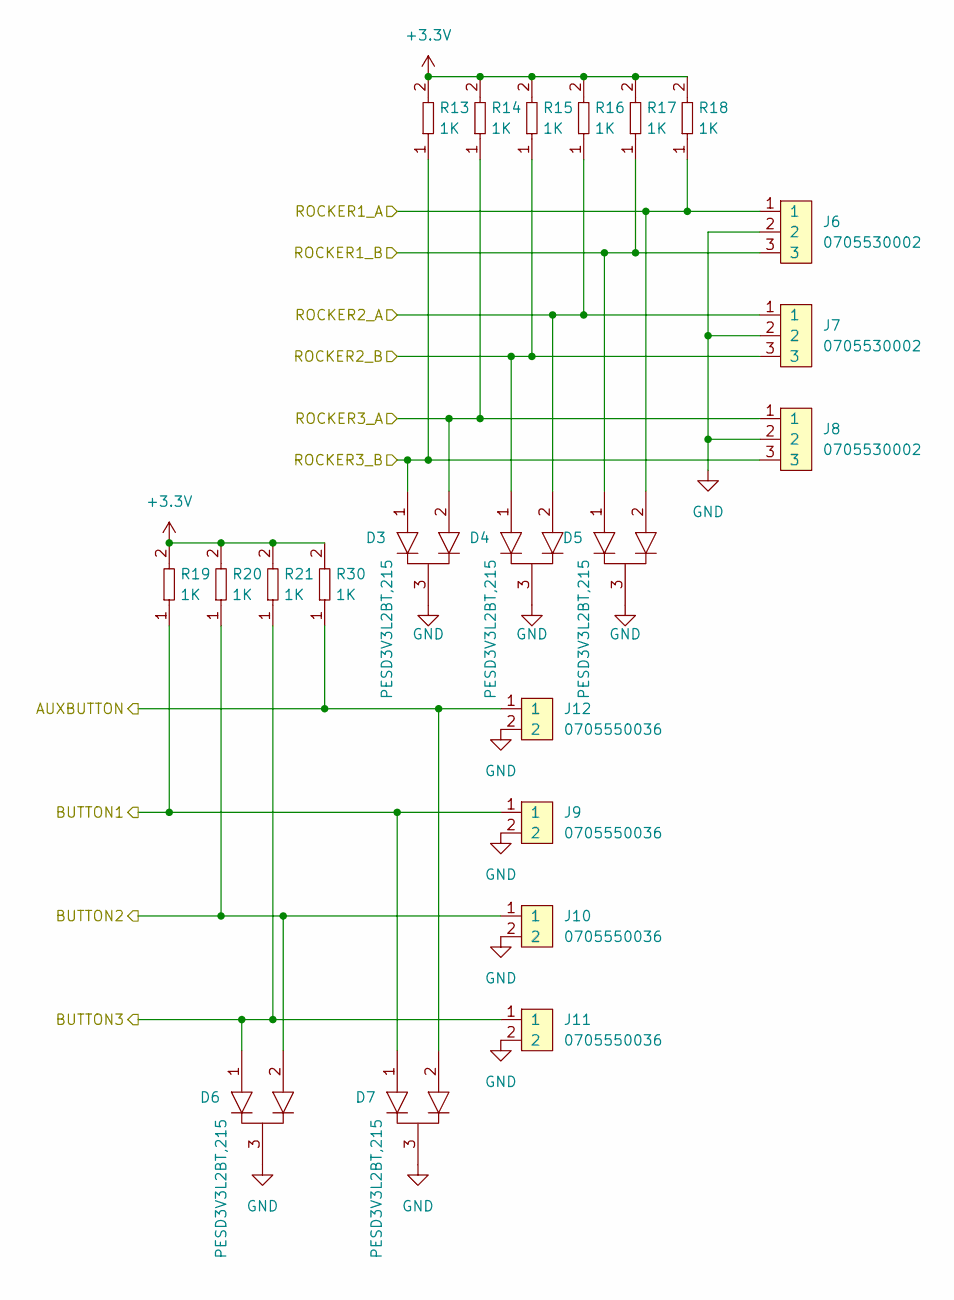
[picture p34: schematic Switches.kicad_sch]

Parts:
D3, D4, D5, D6, D7: PESD3V3L2BT,215; SOT-23; Tolerance *; Voltage *; MFR# PESD3V3L2BT,215
J6, J7, J8: 0705530002; Pin_Header_Angled_1x03_Pitch2.54mm; Tolerance *; Voltage *; MFR# 0705530002
J9, J10, J11, J12: 0705550036; Pin_Header_Angled_1x02_Pitch2.54mm; Tolerance *; Voltage *; MFR# 0705550036
R13, R14, R15, R16, R17, R18, R19, R20, R21, R30: RC0402FR-071KL; R0402; Tolerance 1%; Voltage *; MFR# RC0402FR-071KL

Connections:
+3.3V: R13.2, R14.2, R15.2, R16.2, R17.2, R18.2, R19.2, R20.2, R21.2, R30.2; also elsewhere on the board
/Controls and Switches/AUXBUTTON: D7.2, J12.1, R30.1; also elsewhere on the board
/Controls and Switches/BUTTON1: D7.1, J9.1, R19.1; also elsewhere on the board
/Controls and Switches/BUTTON2: D6.2, J10.1, R20.1; also elsewhere on the board
/Controls and Switches/BUTTON3: D6.1, J11.1, R21.1; also elsewhere on the board
/Controls and Switches/ROCKER1_A: D5.2, J6.1, R18.1; also elsewhere on the board
/Controls and Switches/ROCKER1_B: D5.1, J6.3, R17.1; also elsewhere on the board
/Controls and Switches/ROCKER2_A: D4.2, J7.1, R16.1; also elsewhere on the board
/Controls and Switches/ROCKER2_B: D4.1, J7.3, R15.1; also elsewhere on the board
/Controls and Switches/ROCKER3_A: D3.2, J8.1, R14.1; also elsewhere on the board
/Controls and Switches/ROCKER3_B: D3.1, J8.3, R13.1; also elsewhere on the board
GND: D3.3, D4.3, D5.3, D6.3, D7.3, J6.2, J7.2, J8.2, J9.2, J10.2, J11.2, J12.2; also elsewhere on the board

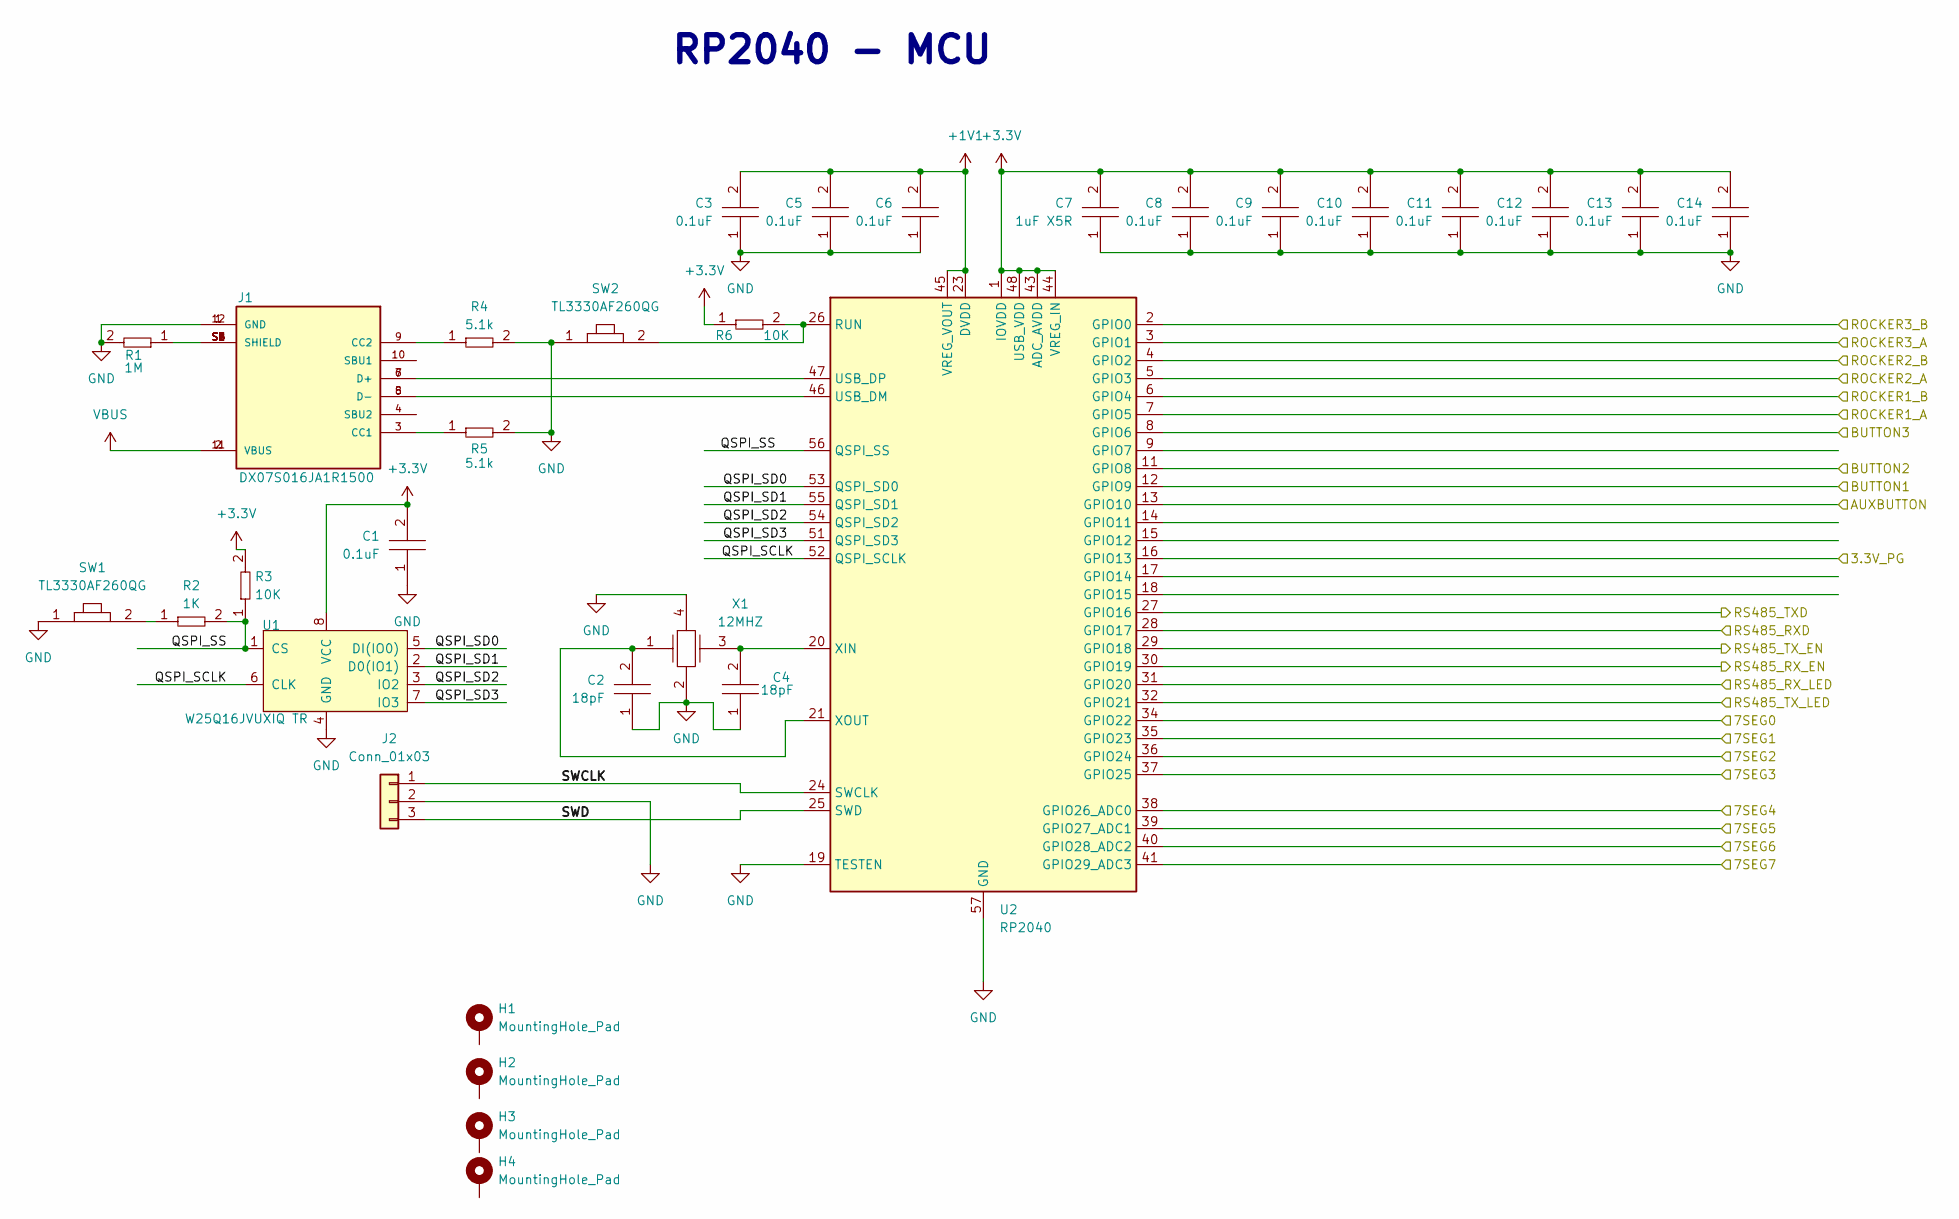
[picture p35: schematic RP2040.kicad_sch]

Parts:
C1, C3, C5, C6, C8, C9, C10, C11, C12, C13, C14: C0402C104K9PACTU; R0402; Tolerance 10%; Voltage 6.3V; MFR# C0402C104K9PACTU
C2, C4: GCM1555C1H180GA16D; C0402; Tolerance 2%; Voltage 50V; MFR# GCM1555C1H180GA16D
C7: CC0603KRX5R7BB105; C0603; Tolerance 10%; Voltage 16V; MFR# CC0603KRX5R7BB105
H1, H2, H3, H4: MountingHole_Pad; RPI_HAT_HOLE
J1: DX07S016JA1R1500; JAE_DX07S016JA1R1500; Tolerance *; Voltage 20V; MFR# DX07S016JA1R1500
J2: Conn_01x03; Pin_Header_Angled_1x03_Pitch2.54mm
R1: RT0603BRD071ML; R0603; Tolerance 1%; Voltage N/A; MFR# RT0603BRD071ML
R2: RC0402FR-071KL; R0402; Tolerance 1%; Voltage *; MFR# RC0402FR-071KL
R3, R6: RC0402FR-0710KL; R0402; Tolerance 1%; Voltage *; MFR# RC0402FR-0710KL
R4, R5: RC0402FR-075K1L; R0402; Tolerance 1%; Voltage N/A; MFR# RC0402FR-075K1L
SW1, SW2: TL3330AF260QG; SW_TL3330AF260QG; Tolerance *; Voltage 12VDC; MFR# TL3330AF260QG
U1: TEMPLATE; PSON50P300X200X60-9N; Tolerance *; Voltage 3.3V; MFR# W25Q16JVUXIQ TR
U2: RP2040; QFN-56-1EP_7x7mm_P0.4mm_EP3.2x3.2mm
X1: ABM8G-12.000MHZ-18-D2Y-T; XTAL_ABM8G-12.000MHZ-18-D2Y-T; Tolerance ±20ppm; Voltage *; MFR# ABM8G-12.000MHZ-18-D2Y-T

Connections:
+1V1: C3.2, C5.2, C6.2, U2.23 (DVDD), U2.45 (VREG_VOUT), U2.50 (DVDD)
+3.3V: C1.2, C7.2, C8.2, C9.2, C10.2, C11.2, C12.2, C13.2, C14.2, R3.2, R6.1, U1.8 (VCC), U2.1 (IOVDD), U2.10 (IOVDD), U2.22 (IOVDD), U2.33 (IOVDD), U2.42 (IOVDD), U2.43 (ADC_AVDD), U2.44 (VREG_IN), U2.48 (USB_VDD), U2.49 (IOVDD); also elsewhere on the board
/7 Segment Display/7SEG0: U2.34 (GPIO22); also elsewhere on the board
/7 Segment Display/7SEG1: U2.35 (GPIO23); also elsewhere on the board
/7 Segment Display/7SEG2: U2.36 (GPIO24); also elsewhere on the board
/7 Segment Display/7SEG3: U2.37 (GPIO25); also elsewhere on the board
/7 Segment Display/7SEG4: U2.38 (GPIO26_ADC0); also elsewhere on the board
/7 Segment Display/7SEG5: U2.39 (GPIO27_ADC1); also elsewhere on the board
/7 Segment Display/7SEG6: U2.40 (GPIO28_ADC2); also elsewhere on the board
/7 Segment Display/7SEG7: U2.41 (GPIO29_ADC3); also elsewhere on the board
/Controls and Switches/AUXBUTTON: U2.13 (GPIO10); also elsewhere on the board
/Controls and Switches/BUTTON1: U2.12 (GPIO9); also elsewhere on the board
/Controls and Switches/BUTTON2: U2.11 (GPIO8); also elsewhere on the board
/Controls and Switches/BUTTON3: U2.8 (GPIO6); also elsewhere on the board
/Controls and Switches/ROCKER1_A: U2.7 (GPIO5); also elsewhere on the board
/Controls and Switches/ROCKER1_B: U2.6 (GPIO4); also elsewhere on the board
/Controls and Switches/ROCKER2_A: U2.5 (GPIO3); also elsewhere on the board
/Controls and Switches/ROCKER2_B: U2.4 (GPIO2); also elsewhere on the board
/Controls and Switches/ROCKER3_A: U2.3 (GPIO1); also elsewhere on the board
/Controls and Switches/ROCKER3_B: U2.2 (GPIO0); also elsewhere on the board
/Power/3.3V_PG: U2.16 (GPIO13); also elsewhere on the board
/RP2040/QSPI_SCLK: U1.6 (CLK), U2.52 (QSPI_SCLK)
/RP2040/QSPI_SD0: U1.5 (DI(IO0)), U2.53 (QSPI_SD0)
/RP2040/QSPI_SD1: U1.2 (D0(IO1)), U2.55 (QSPI_SD1)
/RP2040/QSPI_SD2: U1.3 (IO2), U2.54 (QSPI_SD2)
/RP2040/QSPI_SD3: U1.7 (IO3), U2.51 (QSPI_SD3)
/RP2040/QSPI_SS: R2.2, R3.1, U1.1 (CS), U2.56 (QSPI_SS)
/RP2040/RS485_RXD: U2.28 (GPIO17); also elsewhere on the board
/RP2040/RS485_RX_EN: U2.30 (GPIO19); also elsewhere on the board
/RP2040/RS485_RX_LED: U2.31 (GPIO20); also elsewhere on the board
/RP2040/RS485_TXD: U2.27 (GPIO16); also elsewhere on the board
/RP2040/RS485_TX_EN: U2.29 (GPIO18); also elsewhere on the board
/RP2040/RS485_TX_LED: U2.32 (GPIO21); also elsewhere on the board
/RP2040/SWCLK: J2.1, U2.24 (SWCLK)
/RP2040/SWD: J2.3, U2.25 (SWD)
GND: C1.1, C2.1, C3.1, C4.1, C5.1, C6.1, C7.1, C8.1, C9.1, C10.1, C11.1, C12.1, C13.1, C14.1, J1.1 (GND), J1.12 (GND), J2.2, R1.2, R4.2, R5.2, SW1.1, SW2.1, U1.4 (GND), U2.19 (TESTEN), U2.57 (GND), X1.2, X1.4; also elsewhere on the board
unnamed: J1.3 (CC1), R5.1
unnamed: J1.9 (CC2), R4.1
unnamed: J1.S1 (SHIELD), J1.S2 (SHIELD), J1.S3 (SHIELD), J1.S4 (SHIELD), J1.S5 (SHIELD), J1.S6 (SHIELD), R1.1
unnamed: R2.1, SW1.2
unnamed: R6.2, SW2.2, U2.26 (RUN)
unnamed: J1.5 (D-), J1.8 (D-), U2.46 (USB_DM)
unnamed: J1.6 (D+), J1.7 (D+), U2.47 (USB_DP)
unnamed: C4.2, U2.20 (XIN), X1.3
unnamed: C2.2, U2.21 (XOUT), X1.1
VBUS: J1.2 (VBUS), J1.11 (VBUS)

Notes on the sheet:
RP2040 - MCU

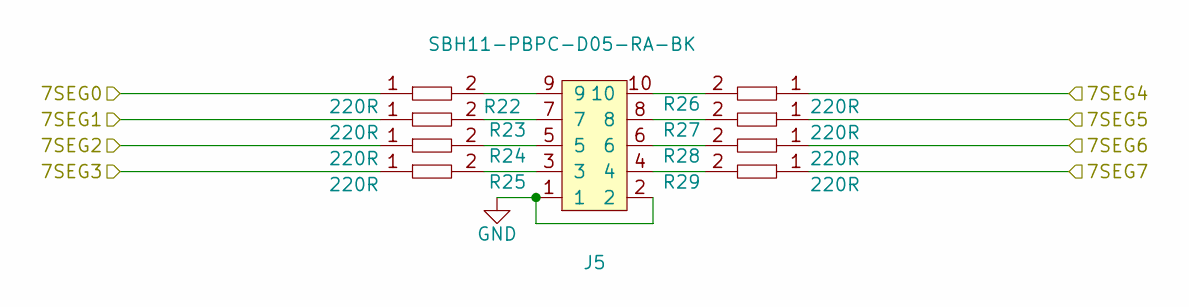
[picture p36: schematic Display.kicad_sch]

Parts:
J5: SBH11-PBPC-D05-RA-BK; CONN10_D05-RA-BK_SUL; Tolerance *; Voltage *; MFR# SBH11-PBPC-D05-RA-BK
R22, R23, R24, R25, R26, R27, R28, R29: RC0402FR-07220RL; R0402; Tolerance 1%; Voltage *; MFR# RC0402FR-07220RL

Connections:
/7 Segment Display/7SEG0: R22.1; also elsewhere on the board
/7 Segment Display/7SEG1: R23.1; also elsewhere on the board
/7 Segment Display/7SEG2: R24.1; also elsewhere on the board
/7 Segment Display/7SEG3: R25.1; also elsewhere on the board
/7 Segment Display/7SEG4: R26.1; also elsewhere on the board
/7 Segment Display/7SEG5: R27.1; also elsewhere on the board
/7 Segment Display/7SEG6: R28.1; also elsewhere on the board
/7 Segment Display/7SEG7: R29.1; also elsewhere on the board
GND: J5.1, J5.2; also elsewhere on the board
unnamed: J5.3, R25.2
unnamed: J5.4, R29.2
unnamed: J5.5, R24.2
unnamed: J5.6, R28.2
unnamed: J5.7, R23.2
unnamed: J5.8, R27.2
unnamed: J5.9, R22.2
unnamed: J5.10, R26.2

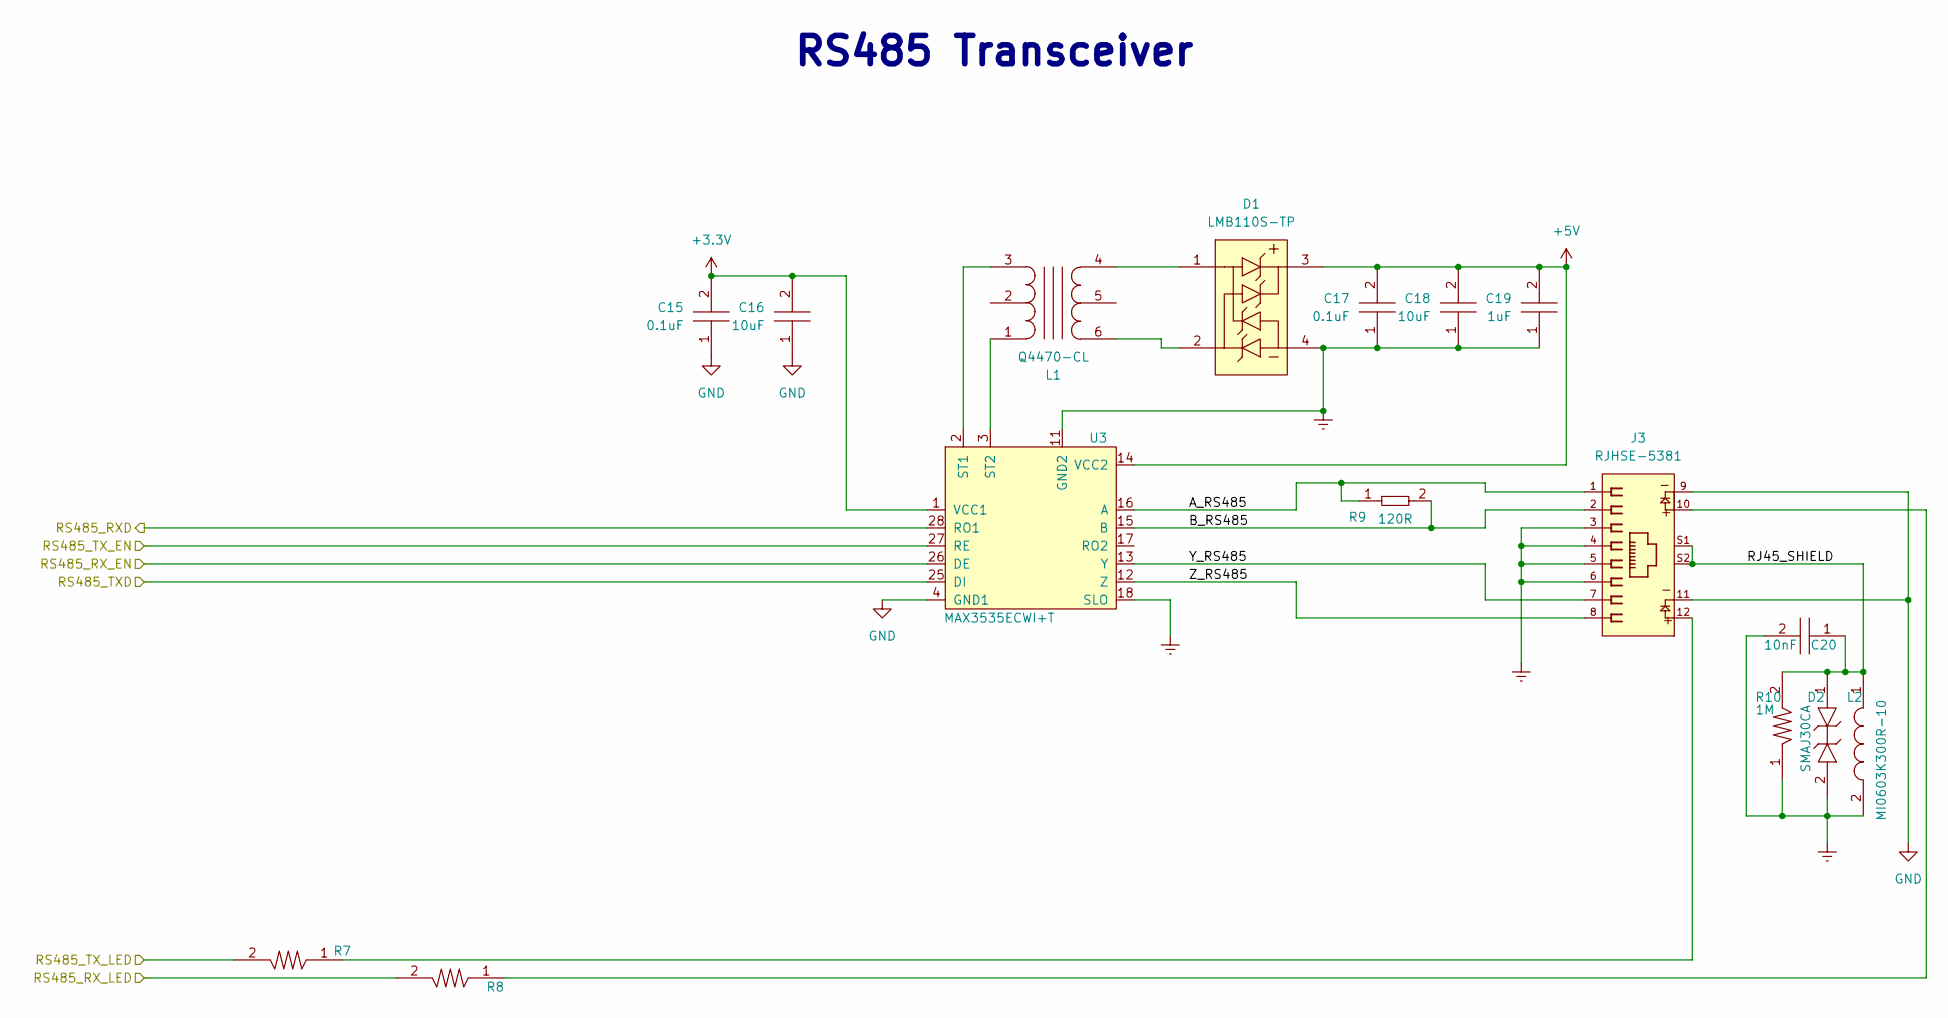
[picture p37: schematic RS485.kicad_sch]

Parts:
C15, C17: CL10B104JB8NNNC; C0603; Tolerance 5%; Voltage 50V; MFR# CL10B104JB8NNNC
C16, C18: CGA5L3X5R1V106K160AB; C1206; Tolerance 10%; Voltage 35V; MFR# CGA5L3X5R1V106K160AB
C19: C1206C105K3RACAUTO; D_SOD-123; Tolerance 10%; Voltage 25V; MFR# C1206C105K3RACAUTO
C20: C0805C103KCRACAUTO; C0805; Tolerance 10%; Voltage 500V; MFR# C0805C103KCRACAUTO
D1: LMB110S-TP; Tolerance *; Voltage 850 mV @ 500 mA; MFR# LMB110S-TP
D2: SMAJ30CA; Tolerance *; Voltage 30V Clamp; MFR# SMAJ30CA
J3: RJHSE-5381; AMPHENOL_RJHSE-5381; Tolerance *; Voltage *; MFR# RJHSE-5381
L1: Q4470-CL; SO6_Q4470-CL_C-SIZE_COC; Tolerance *; Voltage 5V; MFR# Q4470-CL
L2: MI0603K300R-10; Tolerance *; Voltage *; MFR# MI0603K300R-10
R7, R8: RC0603FR-07470RL; R0603; Tolerance 1%; Voltage *; MFR# RC0603FR-07470RL
R9: AC0402FR-07120RL; R0402; Tolerance 1%; Voltage *; MFR# AC0402FR-07120RL
R10: RC1206FR-071ML; R1206; Tolerance 1%; Voltage *; MFR# RC1206FR-071ML
U3: MAX3535ECWI+T; 21-0145_W28M&plus_9_MXM; Tolerance N/A; Voltage 3-5.5V; MFR# MAX3535ECWI+T

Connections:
+3.3V: C15.2, C16.2, U3.1 (VCC1); also elsewhere on the board
+5V: C17.2, C18.2, C19.2, D1.3, U3.14 (VCC2)
/RP2040/RS485_RXD: U3.26 (DE); also elsewhere on the board
/RP2040/RS485_RX_EN: U3.27 (RE); also elsewhere on the board
/RP2040/RS485_RX_LED: R7.2; also elsewhere on the board
/RP2040/RS485_TXD: U3.28 (RO1); also elsewhere on the board
/RP2040/RS485_TX_EN: U3.25 (DI); also elsewhere on the board
/RP2040/RS485_TX_LED: R8.2; also elsewhere on the board
/RS485 Transceiver/A_RS485: J3.1, R9.1, U3.16 (A)
/RS485 Transceiver/B_RS485: J3.2, R9.2, U3.15 (B)
/RS485 Transceiver/RJ45_SHIELD: C20.1, D2.1, J3.S1, J3.S2, L2.1, R10.2
/RS485 Transceiver/Y_RS485: J3.7, U3.13 (Y)
/RS485 Transceiver/Z_RS485: J3.8, U3.12 (Z)
Earth: C17.1, C18.1, C19.1, C20.2, D1.4, D2.2, J3.3, J3.4, J3.5, J3.6, L2.2, R10.1, U3.11 (GND2), U3.18 (SLO)
GND: C15.1, C16.1, J3.9, J3.11, U3.4 (GND1); also elsewhere on the board
unnamed: D1.1, L1.4
unnamed: D1.2, L1.6
unnamed: J3.10, R8.1
unnamed: J3.12, R7.1
unnamed: L1.3, U3.2 (ST1)
unnamed: L1.1, U3.3 (ST2)

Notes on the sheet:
RS485 Transceiver

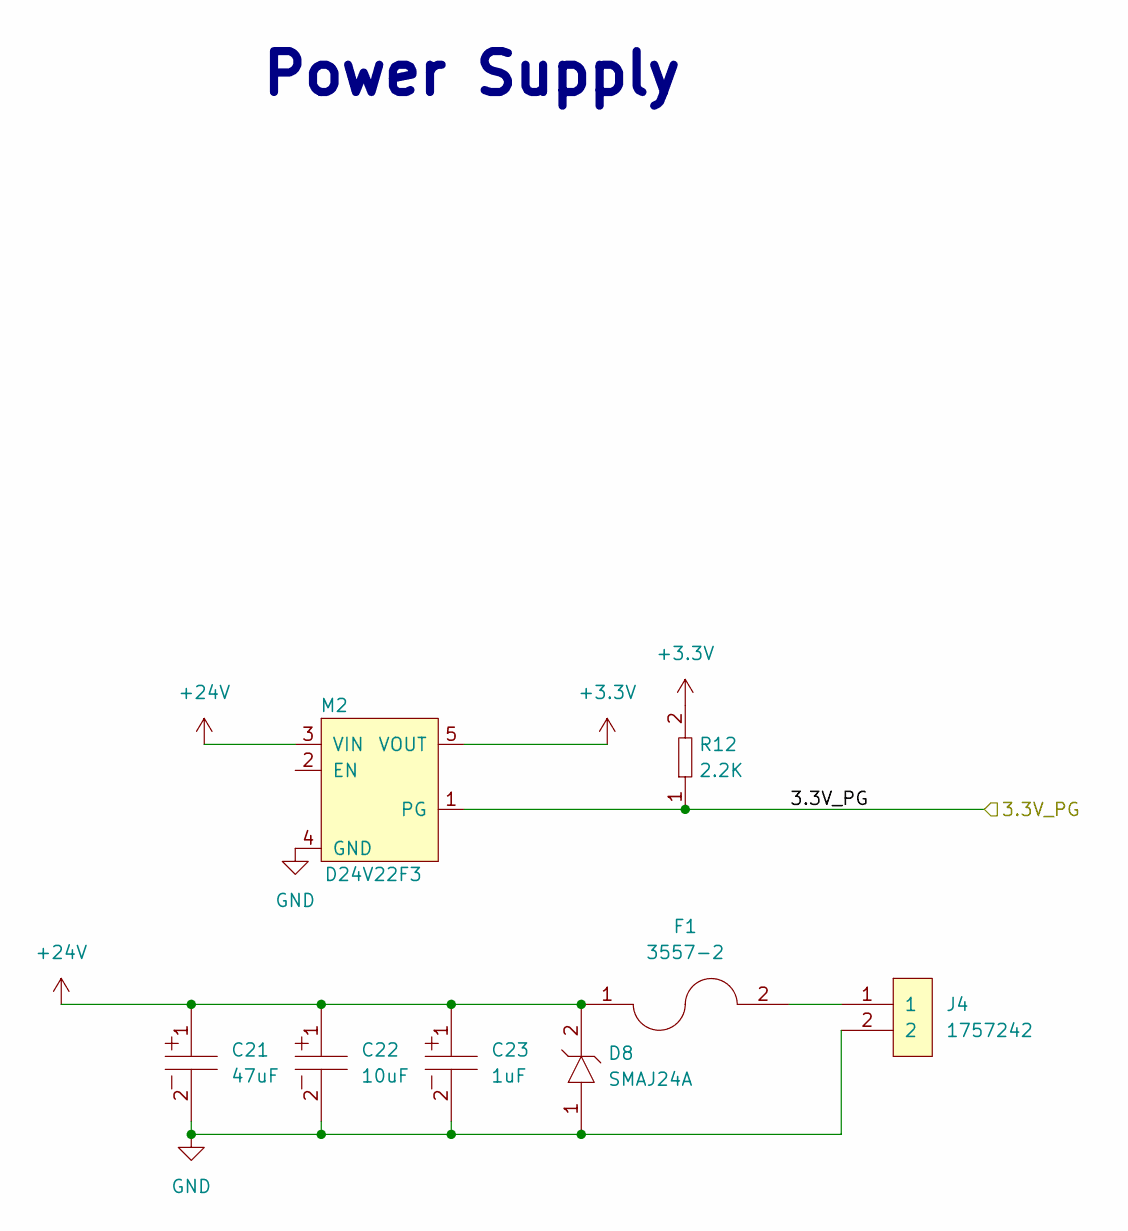
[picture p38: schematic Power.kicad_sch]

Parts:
C21: UUQ1H470MCL1GS; CP_Elec_8x10; Tolerance 20%; Voltage 50V; MFR# UUQ1H470MCL1GS
C22: UUQ1H100MCL1GB; CP_Elec_4x5.3; Tolerance 20%; Voltage 50V; MFR# UUQ1H100MCL1GB
C23: UUQ1H010MCL1GB; CP_Elec_4x5.3; Tolerance 20%; Voltage 50V; MFR# UUQ1H010MCL1GB
D8: SMAJ24A; SMAJ; Tolerance *; Voltage 24V RS, 26.7V VB, 38.9V Clamp; MFR# SMAJ24A
F1: 3557-2; FUSE_3557-2; Tolerance *; Voltage 500V; MFR# 3557-2
J4: 1757242; PhoenixContact_MSTBA-G_02x5.08mm_Angled; Tolerance *; Voltage 300V; MFR# 1757242
M2: D24V22F3; D24V22F12; Tolerance N/A; Voltage 36V IN 3.3V OUT; MFR# D24V22F3
R12: RC0603FR-072K2L; R0603; Tolerance 1%; Voltage N/A; MFR# RC0603FR-072K2L

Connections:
+3.3V: M2.5 (VOUT), R12.2; also elsewhere on the board
+24V: C21.1, C22.1, C23.1, D8.2, F1.1, M2.3 (VIN)
/Power/3.3V_PG: M2.1 (PG), R12.1; also elsewhere on the board
GND: C21.2, C22.2, C23.2, D8.1, J4.2, M2.4 (GND); also elsewhere on the board
unnamed: F1.2, J4.1

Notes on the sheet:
Power Supply

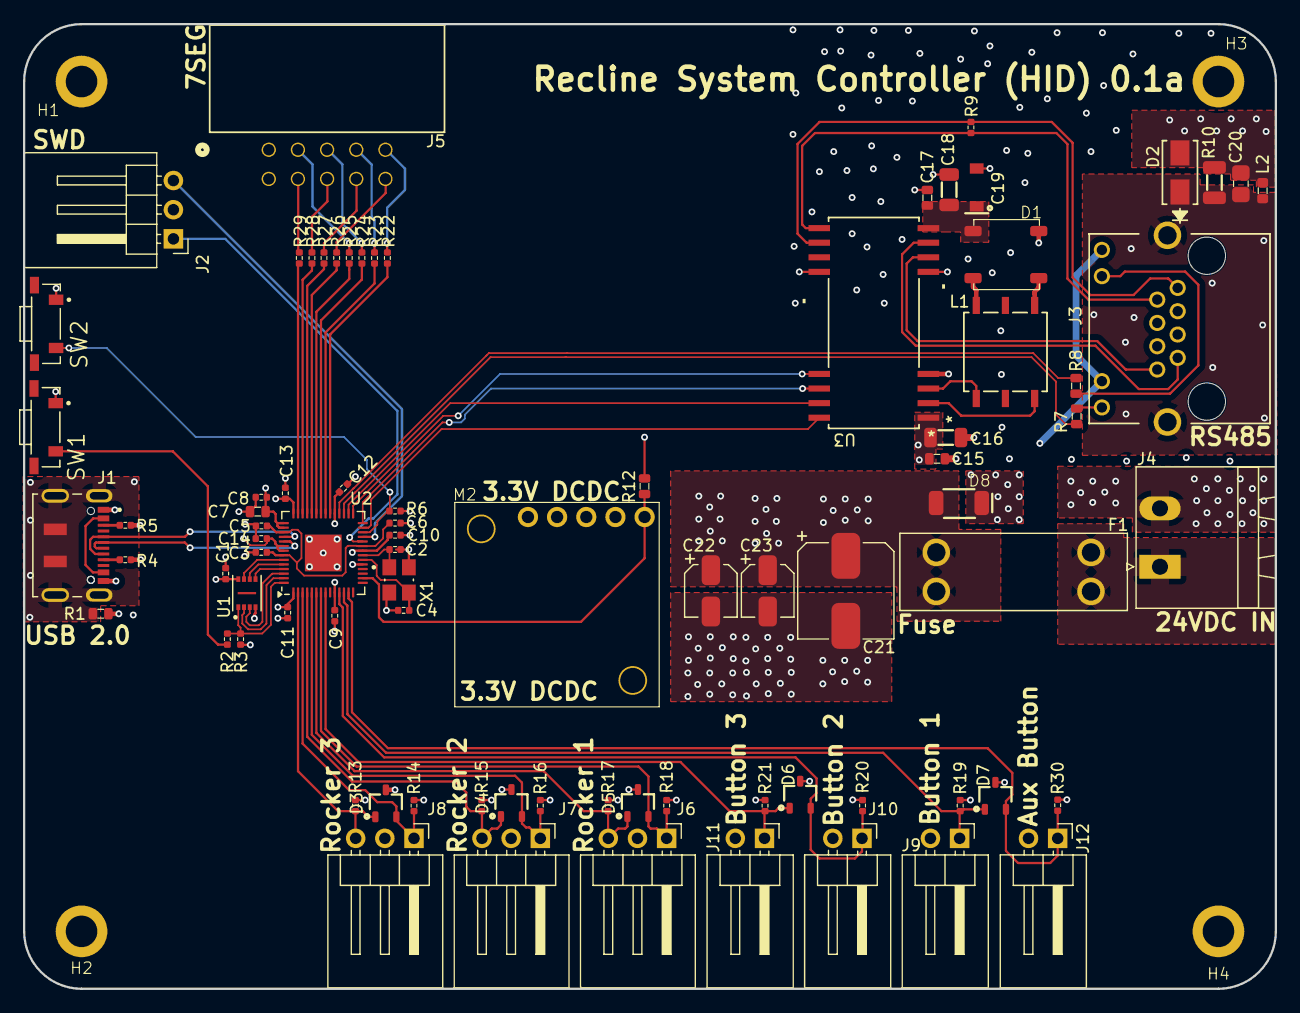
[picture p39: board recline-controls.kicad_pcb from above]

Board: 4 copper layers, 109.0 x 84.0 mm, 86 parts (0 on the bottom side), 69 nets.

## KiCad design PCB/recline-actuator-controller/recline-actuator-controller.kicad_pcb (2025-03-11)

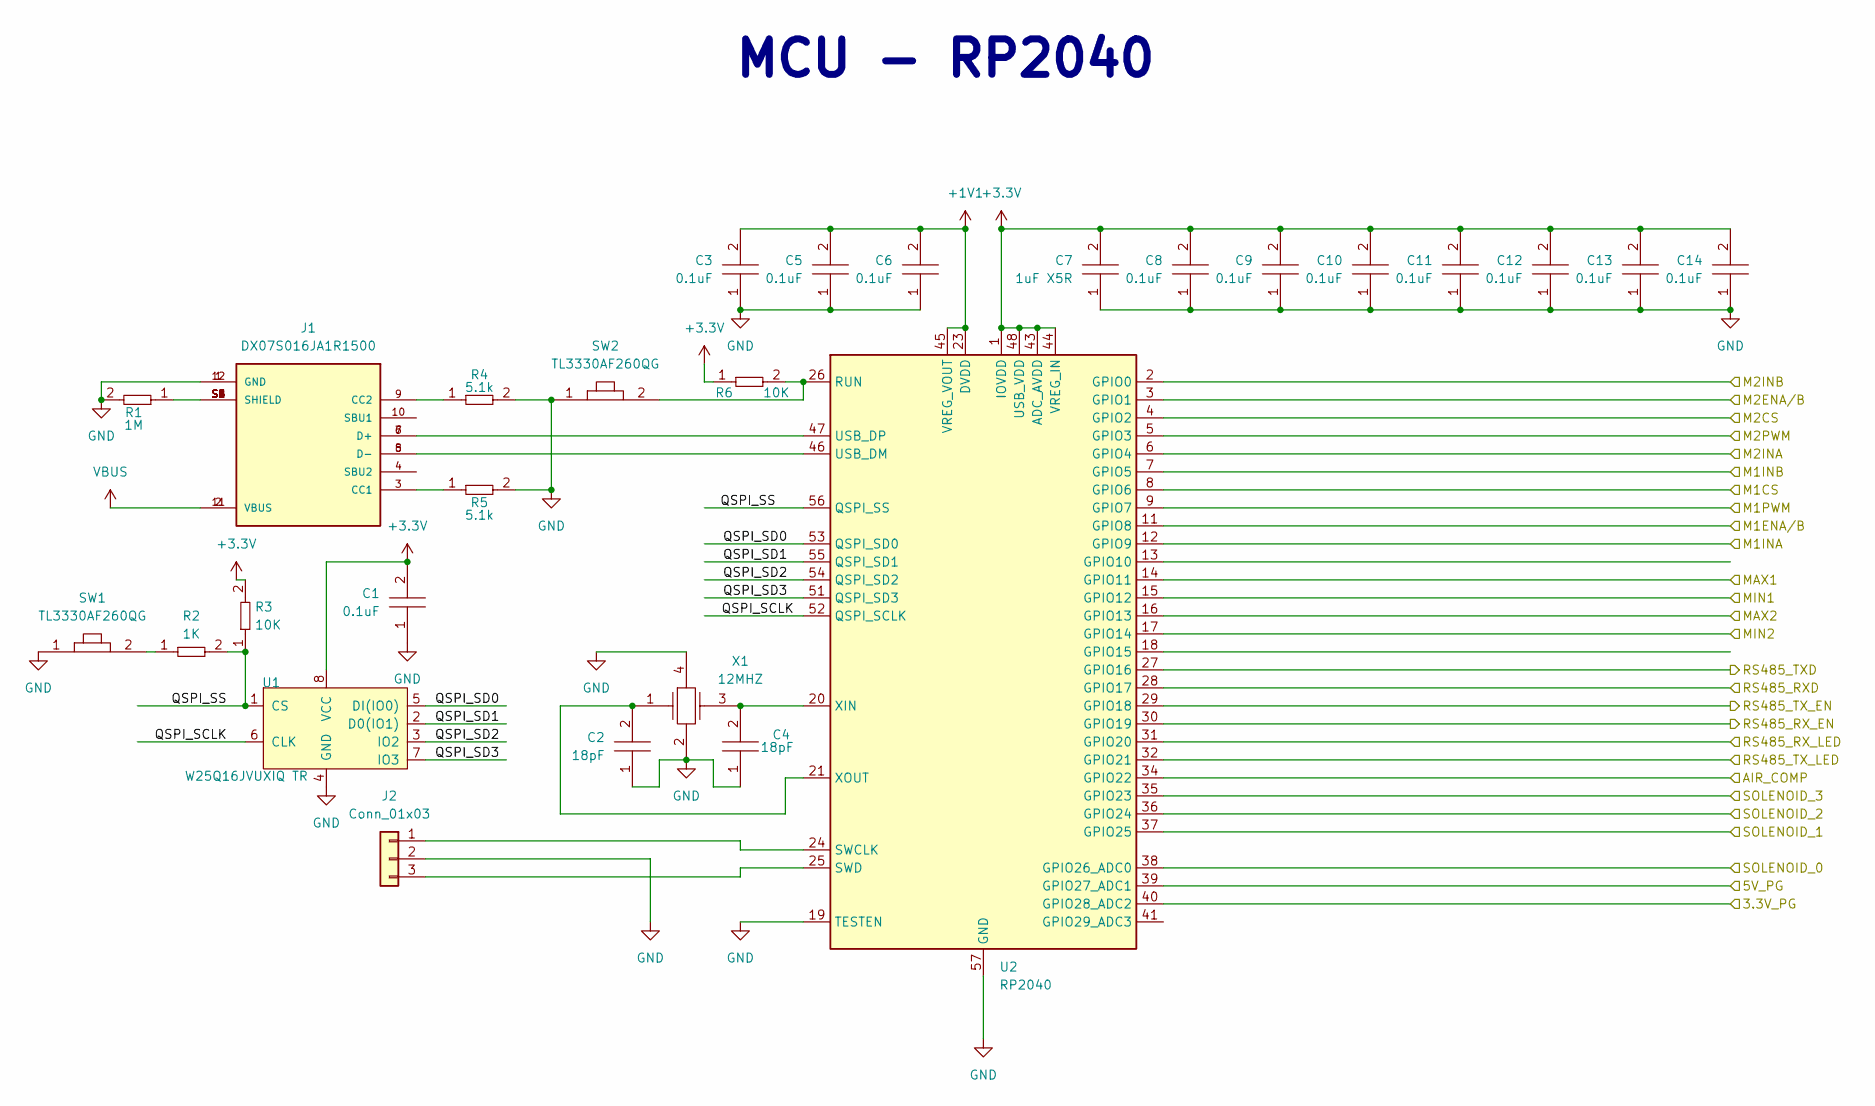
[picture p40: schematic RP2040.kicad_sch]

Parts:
C1, C3, C5, C6, C8, C9, C10, C11, C12, C13, C14: C0402C104K9PACTU; R0402; Tolerance 10%; Voltage 6.3V; MFR# C0402C104K9PACTU
C2, C4: GCM1555C1H180GA16D; C0402; Tolerance 2%; Voltage 50V; MFR# GCM1555C1H180GA16D
C7: CC0603KRX5R7BB105; C0603; Tolerance 10%; Voltage 16V; MFR# CC0603KRX5R7BB105
J1: DX07S016JA1R1500; JAE_DX07S016JA1R1500; Tolerance *; Voltage 20V; MFR# DX07S016JA1R1500
J2: Conn_01x03; PinHeader_1x03_P2.54mm_Vertical
R1: RT0603BRD071ML; R0603; Tolerance 1%; Voltage N/A; MFR# RT0603BRD071ML
R2: RC0402FR-071KL; R0402; Tolerance 1%; Voltage *; MFR# RC0402FR-071KL
R3, R6: RC0402FR-0710KL; R0402; Tolerance 1%; Voltage *; MFR# RC0402FR-0710KL
R4, R5: RC0402FR-075K1L; R0402; Tolerance 1%; Voltage N/A; MFR# RC0402FR-075K1L
SW1, SW2: TL3330AF260QG; SW_TL3330AF260QG; Tolerance *; Voltage 12VDC; MFR# TL3330AF260QG
U1: TEMPLATE; PSON50P300X200X60-9N; Tolerance *; Voltage 3.3V; MFR# W25Q16JVUXIQ TR
U2: RP2040; QFN-56-1EP_7x7mm_P0.4mm_EP3.2x3.2mm
X1: ABM8G-12.000MHZ-18-D2Y-T; XTAL_ABM8G-12.000MHZ-18-D2Y-T; Tolerance ±20ppm; Voltage *; MFR# ABM8G-12.000MHZ-18-D2Y-T

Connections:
+1V1: C3.2, C5.2, C6.2, U2.23 (DVDD), U2.45 (VREG_VOUT), U2.50 (DVDD)
+3.3V: C1.2, C7.2, C8.2, C9.2, C10.2, C11.2, C12.2, C13.2, C14.2, R3.2, R6.1, U1.8 (VCC), U2.1 (IOVDD), U2.10 (IOVDD), U2.22 (IOVDD), U2.33 (IOVDD), U2.42 (IOVDD), U2.43 (ADC_AVDD), U2.44 (VREG_IN), U2.48 (USB_VDD), U2.49 (IOVDD); also elsewhere on the board
/Leg Lift Motors/M3CS: U2.40 (GPIO28_ADC2); also elsewhere on the board
/Leg Lift Motors/M3ENA/B: U2.7 (GPIO5); also elsewhere on the board
/Leg Lift Motors/M3INA: U2.9 (GPIO7); also elsewhere on the board
/Leg Lift Motors/M3INB: U2.6 (GPIO4); also elsewhere on the board
/Leg Lift Motors/M3PWM: U2.8 (GPIO6); also elsewhere on the board
/Leg Lift Motors/M4CS: U2.41 (GPIO29_ADC3); also elsewhere on the board
/Leg Lift Motors/M4ENA/B: U2.4 (GPIO2); also elsewhere on the board
/Leg Lift Motors/M4INA: U2.5 (GPIO3); also elsewhere on the board
/Leg Lift Motors/M4INB: U2.2 (GPIO0); also elsewhere on the board
/Leg Lift Motors/M4PWM: U2.3 (GPIO1); also elsewhere on the board
/Motor H-Bridges/M1CS: U2.38 (GPIO26_ADC0); also elsewhere on the board
/Motor H-Bridges/M1ENA/B: U2.17 (GPIO14); also elsewhere on the board
/Motor H-Bridges/M1INA: U2.18 (GPIO15); also elsewhere on the board
/Motor H-Bridges/M1INB: U2.15 (GPIO12); also elsewhere on the board
/Motor H-Bridges/M1PWM: U2.16 (GPIO13); also elsewhere on the board
/Motor H-Bridges/M2CS: U2.39 (GPIO27_ADC1); also elsewhere on the board
/Motor H-Bridges/M2ENA/B: U2.12 (GPIO9); also elsewhere on the board
/Motor H-Bridges/M2INA: U2.14 (GPIO11); also elsewhere on the board
/Motor H-Bridges/M2INB: U2.11 (GPIO8); also elsewhere on the board
/Motor H-Bridges/M2PWM: U2.13 (GPIO10); also elsewhere on the board
/RP2040/QSPI_SCLK: U1.6 (CLK), U2.52 (QSPI_SCLK)
/RP2040/QSPI_SD0: U1.5 (DI(IO0)), U2.53 (QSPI_SD0)
/RP2040/QSPI_SD1: U1.2 (D0(IO1)), U2.55 (QSPI_SD1)
/RP2040/QSPI_SD2: U1.3 (IO2), U2.54 (QSPI_SD2)
/RP2040/QSPI_SD3: U1.7 (IO3), U2.51 (QSPI_SD3)
/RP2040/QSPI_SS: R2.2, R3.1, U1.1 (CS), U2.56 (QSPI_SS)
/RP2040/RS485_RXD: U2.28 (GPIO17); also elsewhere on the board
/RP2040/RS485_RX_EN: U2.30 (GPIO19); also elsewhere on the board
/RP2040/RS485_RX_LED: U2.36 (GPIO24); also elsewhere on the board
/RP2040/RS485_TXD: U2.27 (GPIO16); also elsewhere on the board
/RP2040/RS485_TX_EN: U2.29 (GPIO18); also elsewhere on the board
/RP2040/RS485_TX_LED: U2.37 (GPIO25); also elsewhere on the board
/RP2040/SPI0_CSn: U2.32 (GPIO21); also elsewhere on the board
/RP2040/SPI0_RX: U2.31 (GPIO20); also elsewhere on the board
/RP2040/SPI0_SCK: U2.34 (GPIO22); also elsewhere on the board
unnamed: J1.3 (CC1), R5.1
unnamed: J1.9 (CC2), R4.1
unnamed: J1.S1 (SHIELD), J1.S2 (SHIELD), J1.S3 (SHIELD), J1.S4 (SHIELD), J1.S5 (SHIELD), J1.S6 (SHIELD), R1.1
unnamed: J2.1, U2.24 (SWCLK)
unnamed: J2.3, U2.25 (SWD)
unnamed: R2.1, SW1.2
unnamed: R6.2, SW2.2, U2.26 (RUN)
unnamed: J1.5 (D-), J1.8 (D-), U2.46 (USB_DM)
unnamed: J1.6 (D+), J1.7 (D+), U2.47 (USB_DP)
unnamed: C4.2, U2.20 (XIN), X1.3
unnamed: C2.2, U2.21 (XOUT), X1.1
VBUS: J1.2 (VBUS), J1.11 (VBUS)

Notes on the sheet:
MCU - RP2040

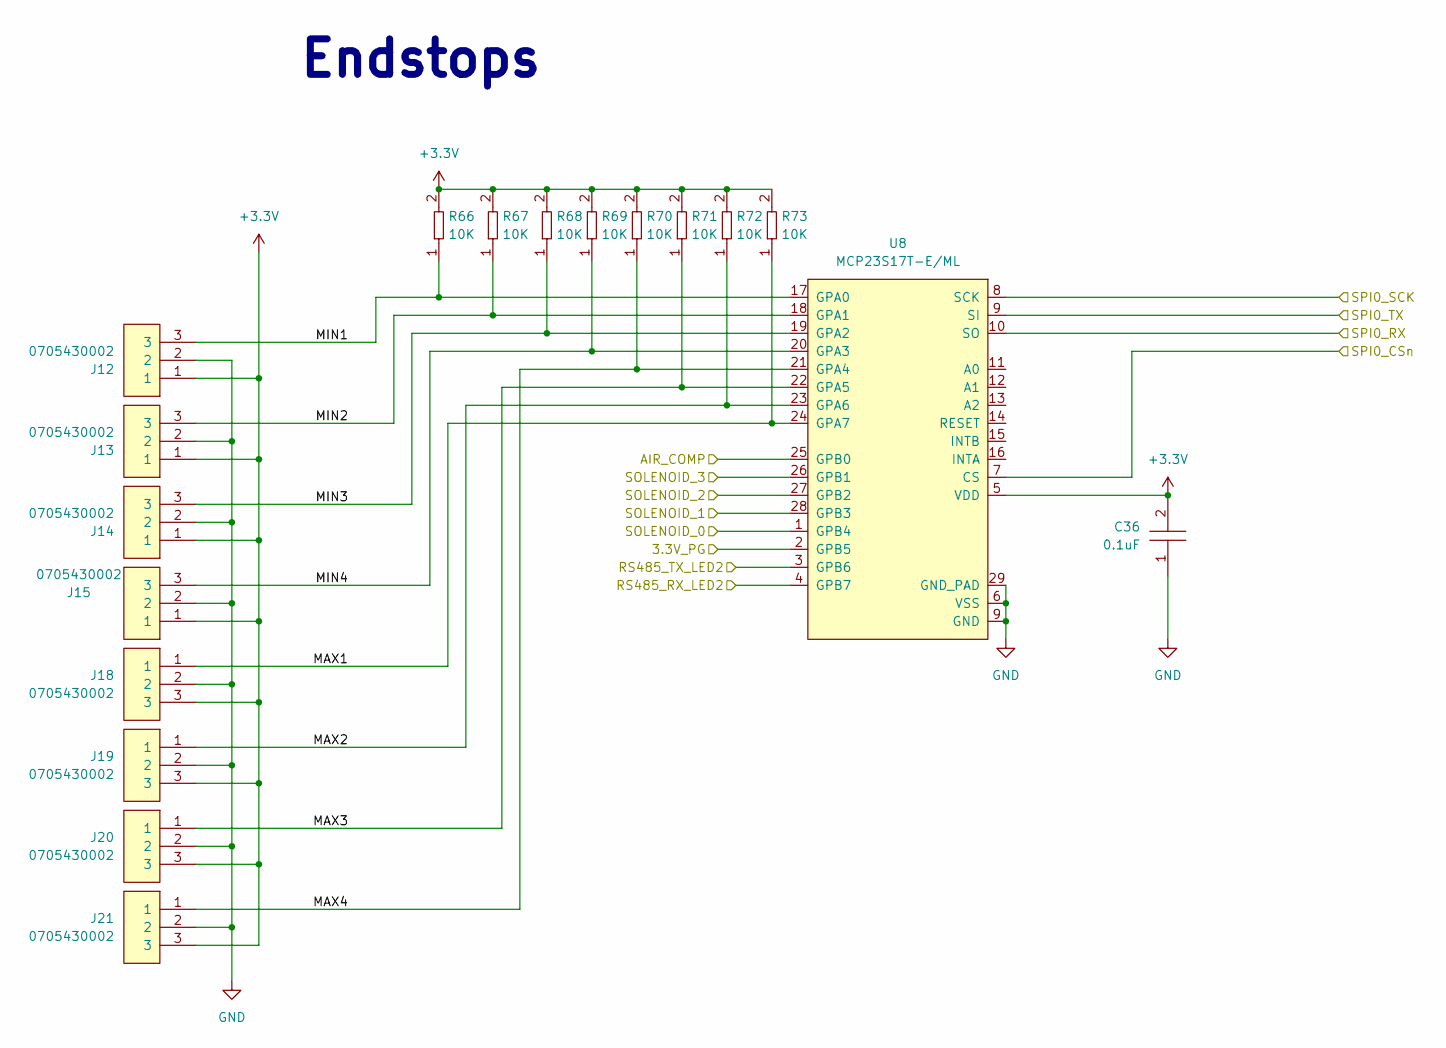
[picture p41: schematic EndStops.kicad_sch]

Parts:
C36: C0402C104K9PACTU; R0402; Tolerance 10%; Voltage 6.3V; MFR# C0402C104K9PACTU
J12, J13, J14, J15, J18, J19, J20, J21: 0705430002; Shrouded_Pin_Header_Straight_1x03_Pitch2.54mm; Tolerance *; Voltage 250V; MFR# 0705430002
R66, R67, R68, R69, R70, R71, R72, R73: RC0402FR-0710KL; R0402; Tolerance 1%; Voltage *; MFR# RC0402FR-0710KL
U8: MCP23S17T-E/ML; QFN28_6x6MC_MCH-L; Tolerance *; Voltage 1.8V-5.5V; MFR# MCP23S17T-E/ML

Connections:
+3.3V: C36.2, J12.1, J13.1, J14.1, J15.1, J18.3, J19.3, J20.3, J21.3, R66.2, R67.2, R68.2, R69.2, R70.2, R71.2, R72.2, R73.2, U8.5 (VDD); also elsewhere on the board
/End Stop Limit Switches/AIR_COMP: U8.25 (GPB0); also elsewhere on the board
/End Stop Limit Switches/MAX1: J18.1, R73.1, U8.24 (GPA7)
/End Stop Limit Switches/MAX2: J19.1, R72.1, U8.23 (GPA6)
/End Stop Limit Switches/MAX3: J20.1, R71.1, U8.22 (GPA5)
/End Stop Limit Switches/MAX4: J21.1, R70.1, U8.21 (GPA4)
/End Stop Limit Switches/MIN1: J12.3, R66.1, U8.17 (GPA0)
/End Stop Limit Switches/MIN2: J13.3, R67.1, U8.18 (GPA1)
/End Stop Limit Switches/MIN3: J14.3, R68.1, U8.19 (GPA2)
/End Stop Limit Switches/MIN4: J15.3, R69.1, U8.20 (GPA3)
/End Stop Limit Switches/RS485_RX_LED2: U8.4 (GPB7); also elsewhere on the board
/End Stop Limit Switches/RS485_TX_LED2: U8.3 (GPB6); also elsewhere on the board
/End Stop Limit Switches/SOLENOID_0: U8.1 (GPB4); also elsewhere on the board
/End Stop Limit Switches/SOLENOID_1: U8.28 (GPB3); also elsewhere on the board
/End Stop Limit Switches/SOLENOID_2: U8.27 (GPB2); also elsewhere on the board
/End Stop Limit Switches/SOLENOID_3: U8.26 (GPB1); also elsewhere on the board
/Power/3.3V_PG: U8.2 (GPB5); also elsewhere on the board
/RP2040/SPI0_CSn: U8.7 (CS); also elsewhere on the board
/RP2040/SPI0_RX: U8.10 (SO); also elsewhere on the board
/RP2040/SPI0_SCK: U8.8 (SCK); also elsewhere on the board

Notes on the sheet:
Endstops

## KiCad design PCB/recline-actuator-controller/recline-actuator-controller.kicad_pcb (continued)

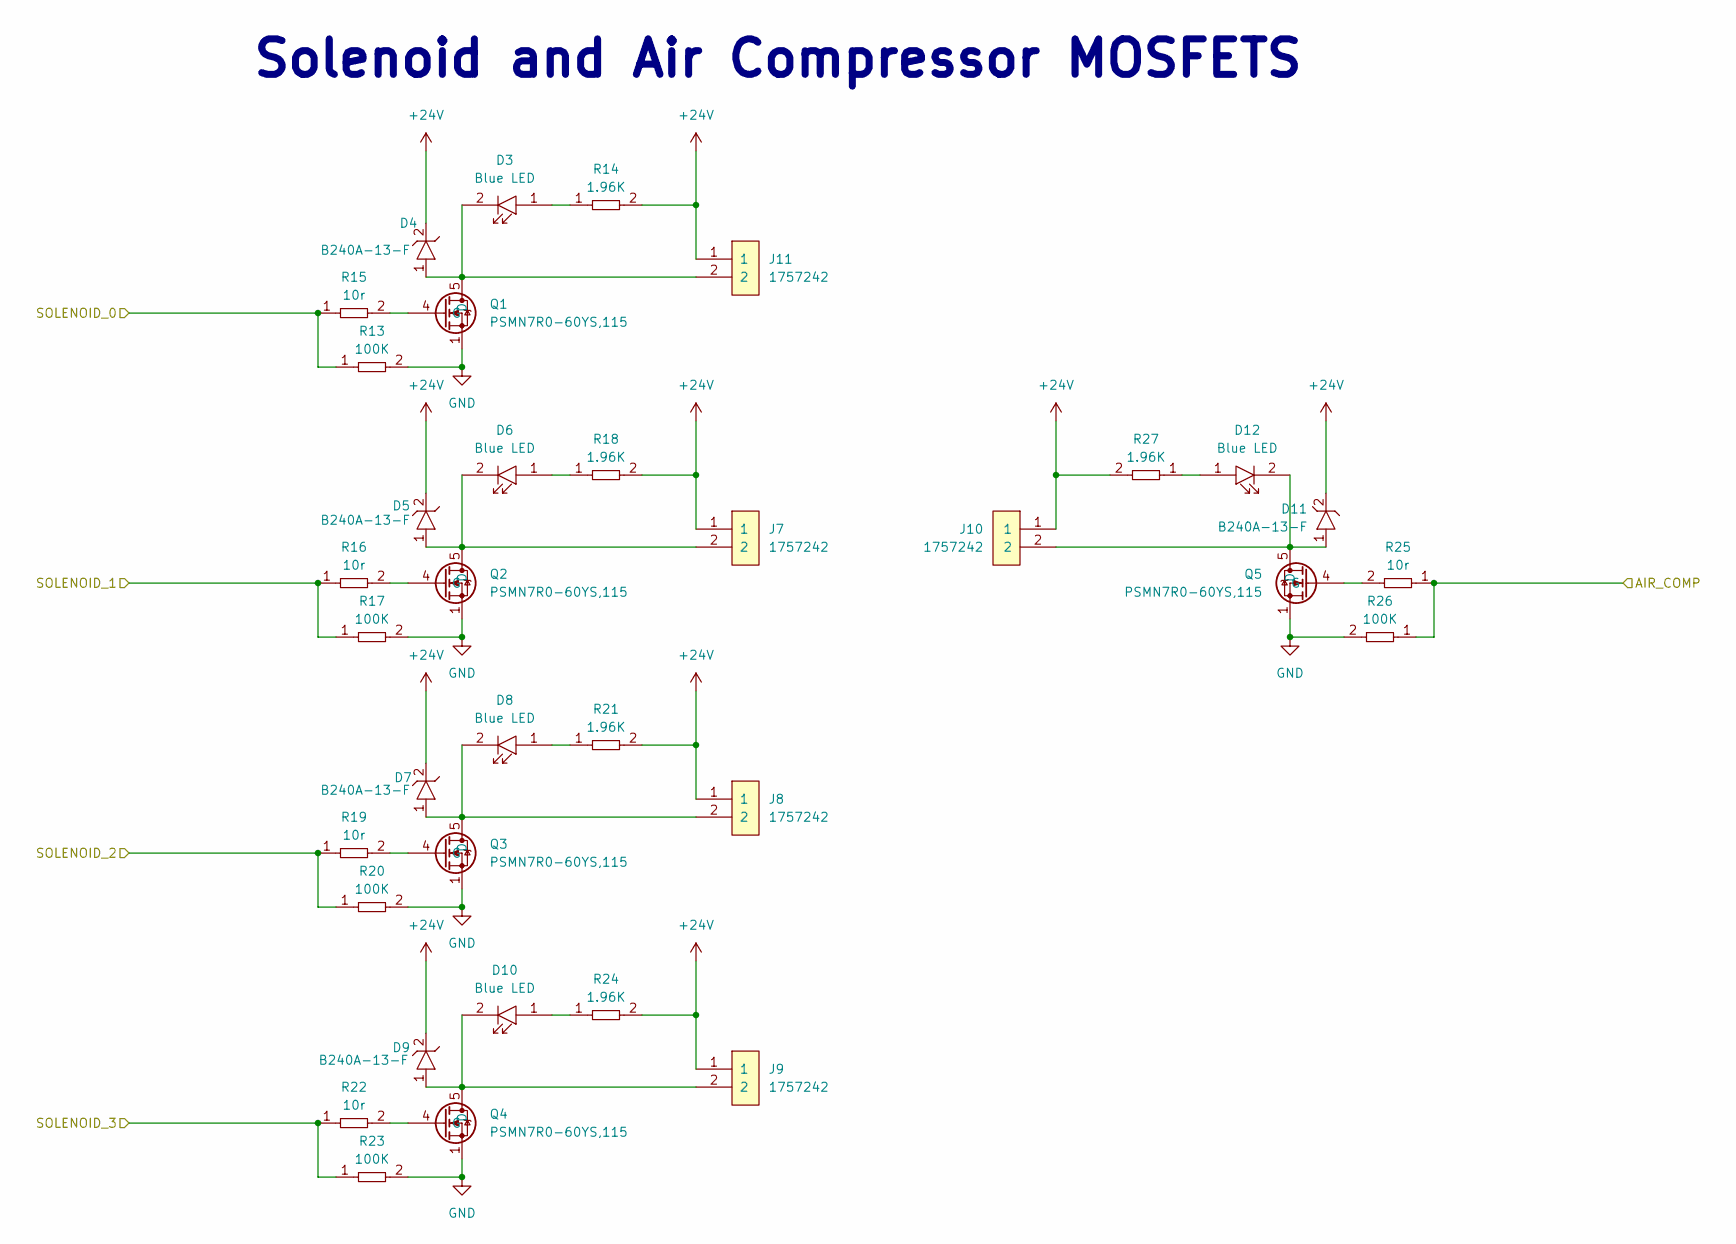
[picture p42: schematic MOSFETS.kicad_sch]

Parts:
D3, D6, D8, D10, D12: LTST-C194TBKT; LED0603; Tolerance *; Voltage 3.3V; MFR# LTST-C194TBKT
D4, D5, D7, D9, D11: B240A-13-F; Tolerance *; Voltage 40V; MFR# B240A-13-F
J7, J8, J9, J10, J11: 1757242; PhoenixContact_MSTBA-G_02x5.08mm_Angled; Tolerance *; Voltage 300V; MFR# 1757242
Q1, Q2, Q3, Q4, Q5: PSMN7R0-60YS,115; IC5_PSMN7R0-60YS_115_NEX-L; Tolerance *; Voltage 60V; MFR# PSMN7R0-60YS,115
R13, R17, R20, R23, R26: RC0805FR-07100KL; R0805; Tolerance 1%; Voltage *; MFR# RC0805FR-07100KL
R14, R18, R21, R24, R27: RC0805FR-071K96L; R0805; Tolerance 1%; Voltage N/A; MFR# RC0805FR-071K96L
R15, R16, R19, R22, R25: RC0805FR-0710RL; R0805; Tolerance 1%; Voltage *; MFR# RC0805FR-0710RL

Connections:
+24V: D4.2, D5.2, D7.2, D9.2, D11.2, J7.1, J8.1, J9.1, J10.1, J11.1, R14.2, R18.2, R21.2, R24.2, R27.2; also elsewhere on the board
/End Stop Limit Switches/AIR_COMP: R25.1, R26.1; also elsewhere on the board
/End Stop Limit Switches/SOLENOID_0: R13.1, R15.1; also elsewhere on the board
/End Stop Limit Switches/SOLENOID_1: R16.1, R17.1; also elsewhere on the board
/End Stop Limit Switches/SOLENOID_2: R19.1, R20.1; also elsewhere on the board
/End Stop Limit Switches/SOLENOID_3: R22.1, R23.1; also elsewhere on the board
unnamed: D3.1, R14.1
unnamed: D6.1, R18.1
unnamed: D8.1, R21.1
unnamed: D10.1, R24.1
unnamed: D12.1, R27.1
unnamed: D3.2, D4.1, J11.2, Q1.5 (D)
unnamed: Q1.4 (G), R15.2
unnamed: D5.1, D6.2, J7.2, Q2.5 (D)
unnamed: Q2.4 (G), R16.2
unnamed: D7.1, D8.2, J8.2, Q3.5 (D)
unnamed: Q3.4 (G), R19.2
unnamed: D9.1, D10.2, J9.2, Q4.5 (D)
unnamed: Q4.4 (G), R22.2
unnamed: D11.1, D12.2, J10.2, Q5.5 (D)
unnamed: Q5.4 (G), R25.2

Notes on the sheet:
Solenoid and Air Compressor MOSFETS

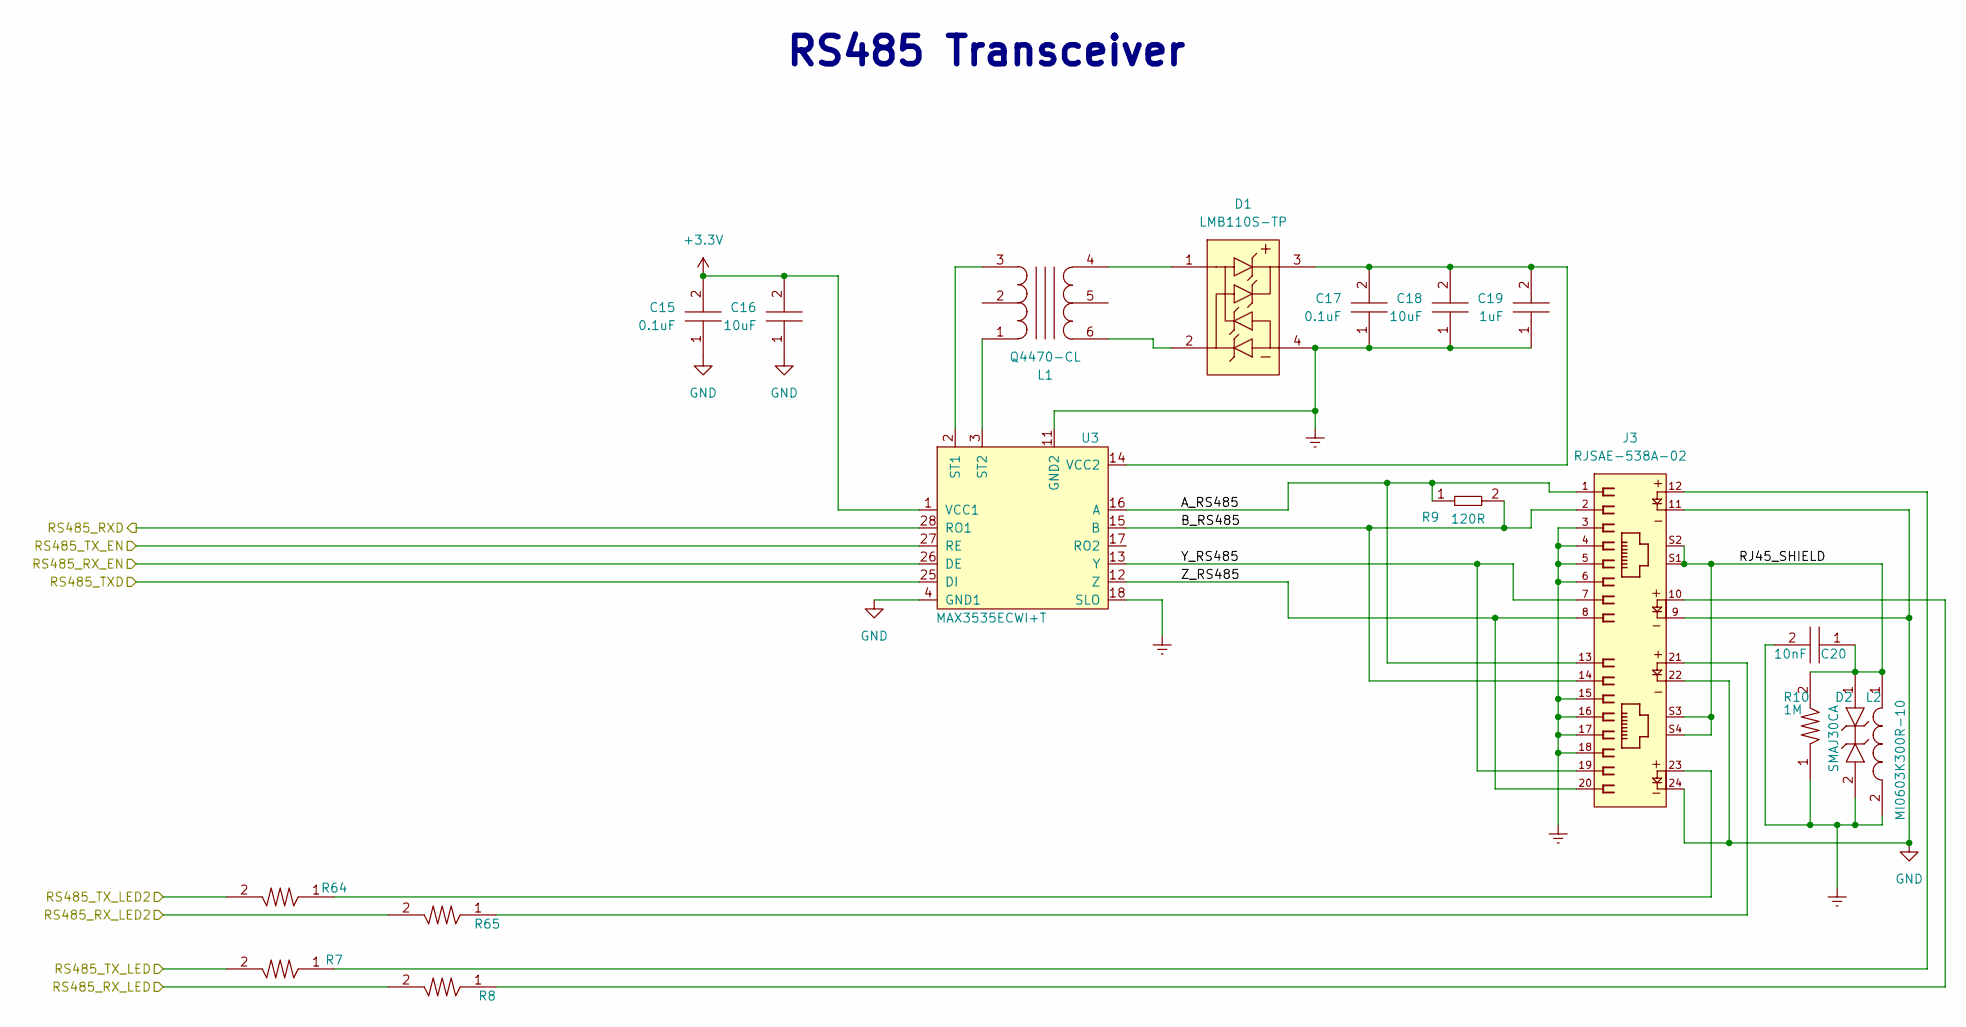
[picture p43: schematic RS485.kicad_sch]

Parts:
C15, C17: CL10B104JB8NNNC; C0603; Tolerance 5%; Voltage 50V; MFR# CL10B104JB8NNNC
C16, C18: CGA5L3X5R1V106K160AB; C1206; Tolerance 10%; Voltage 35V; MFR# CGA5L3X5R1V106K160AB
C19: C1206C105K3RACAUTO; D_SOD-123; Tolerance 10%; Voltage 25V; MFR# C1206C105K3RACAUTO
C20: C0805C103KCRACAUTO; C0805; Tolerance 10%; Voltage 500V; MFR# C0805C103KCRACAUTO
D1: LMB110S-TP; Tolerance *; Voltage 850 mV @ 500 mA; MFR# LMB110S-TP
D2: SMAJ30CA; Tolerance *; Voltage 30V Clamp; MFR# SMAJ30CA
J3: RJSAE-538A-02; AMPHENOL_RJSAE538A02; Tolerance N/A; Voltage *; MFR# RJSAE-538A-02
L1: Q4470-CL; SO6_Q4470-CL_C-SIZE_COC; Tolerance *; Voltage 5V; MFR# Q4470-CL
L2: MI0603K300R-10; Tolerance *; Voltage *; MFR# MI0603K300R-10
R7, R8, R64, R65: RC0603FR-07470RL; R0603; Tolerance 1%; Voltage *; MFR# RC0603FR-07470RL
R9: AC0402FR-07120RL; R0402; Tolerance 1%; Voltage *; MFR# AC0402FR-07120RL
R10: RC1206FR-071ML; R1206; Tolerance 1%; Voltage *; MFR# RC1206FR-071ML
U3: MAX3535ECWI+T; 21-0145_W28M&plus_9_MXM; Tolerance N/A; Voltage 3-5.5V; MFR# MAX3535ECWI+T

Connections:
+3.3V: C15.2, C16.2, U3.1 (VCC1); also elsewhere on the board
/End Stop Limit Switches/RS485_RX_LED2: R65.2; also elsewhere on the board
/End Stop Limit Switches/RS485_TX_LED2: R64.2; also elsewhere on the board
/RP2040/RS485_RXD: U3.28 (RO1); also elsewhere on the board
/RP2040/RS485_RX_EN: U3.26 (DE); also elsewhere on the board
/RP2040/RS485_RX_LED: R8.2; also elsewhere on the board
/RP2040/RS485_TXD: U3.25 (DI); also elsewhere on the board
/RP2040/RS485_TX_EN: U3.27 (RE); also elsewhere on the board
/RP2040/RS485_TX_LED: R7.2; also elsewhere on the board
/RS485 Transceiver/A_RS485: J3.1, J3.13, R9.1, U3.16 (A)
/RS485 Transceiver/B_RS485: J3.2, J3.14, R9.2, U3.15 (B)
/RS485 Transceiver/RJ45_SHIELD: C20.1, D2.1, J3.S1, J3.S2, J3.S3, J3.S4, L2.1, R10.2
/RS485 Transceiver/Y_RS485: J3.7, J3.19, U3.13 (Y)
/RS485 Transceiver/Z_RS485: J3.8, J3.20, U3.12 (Z)
Earth: C17.1, C18.1, C19.1, C20.2, D1.4, D2.2, J3.3, J3.4, J3.5, J3.6, J3.15, J3.16, J3.17, J3.18, L2.2, R10.1, U3.11 (GND2), U3.18 (SLO)
unnamed: D1.1, L1.4
unnamed: D1.2, L1.6
unnamed: J3.10, R8.1
unnamed: J3.12, R7.1
unnamed: J3.21, R65.1
unnamed: J3.23, R64.1
unnamed: L1.3, U3.2 (ST1)
unnamed: L1.1, U3.3 (ST2)
unnamed: C17.2, C18.2, C19.2, D1.3, U3.14 (VCC2)

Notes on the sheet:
RS485 Transceiver

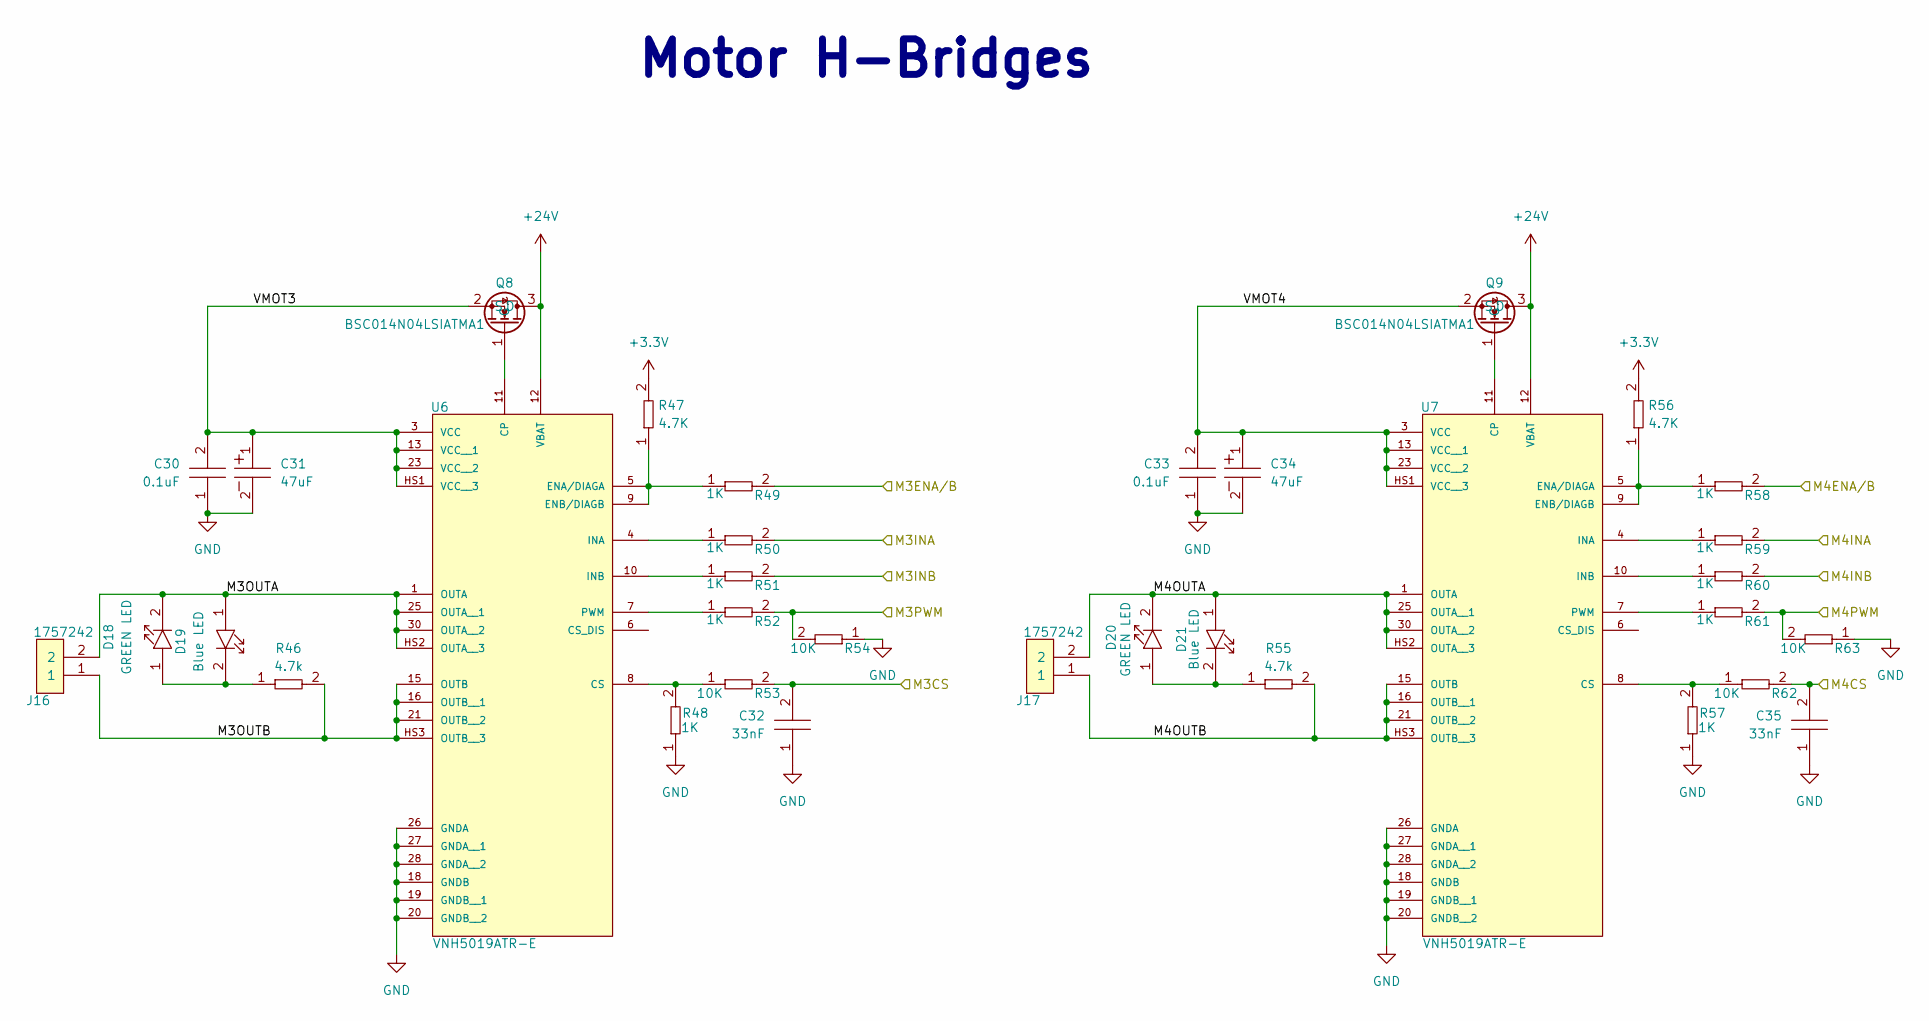
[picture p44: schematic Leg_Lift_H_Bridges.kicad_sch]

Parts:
C30, C33: CL21B104KBFNNNE; C0805; Tolerance 10%; Voltage 50V; MFR# Samsung Electro-Mechanics
C31, C34: UUQ1H470MCL1GS; CP_Elec_8x10; Tolerance 20%; Voltage 50V; MFR# UUQ1H470MCL1GS
C32, C35: C0402C333K4REC7867; C0402; Tolerance 10%; Voltage 16V; MFR# C0402C333K4REC7867
D18, D20: LTST-C194KGKT; LED0603; Tolerance *; Voltage 2.1V; MFR# LTST-C194KGKT
D19, D21: LTST-C194TBKT; LED0603; Tolerance *; Voltage 3.3V; MFR# LTST-C194TBKT
J16, J17: 1757242; PhoenixContact_MSTBA-G_02x5.08mm_Angled; Tolerance *; Voltage 300V; MFR# 1757242
Q8, Q9: BSC014N04LSIATMA1; PG-TDSON-8_INF; Tolerance N/A; Voltage 40V; MFR# BSC014N04LSIATMA1
R46, R55: RC0805FR-074K7L; R0805; Tolerance 1%; Voltage *; MFR# RC0805FR-074K7L
R47, R56: RC0402FR-074K7L; R0402; Tolerance 1%; Voltage *; MFR# RC0402FR-074K7L
R48, R49, R50, R51, R52, R57, R58, R59, R60, R61: RC0402FR-071KL; R0402; Tolerance 1%; Voltage *; MFR# RC0402FR-071KL
R53, R54, R62, R63: RC0402FR-0710KL; R0402; Tolerance 1%; Voltage *; MFR# RC0402FR-0710KL
U6, U7: VNH5019ATR-E; IC_VNH5019ATR-E; Tolerance *; Voltage 24; MFR# VNH5019ATR-E

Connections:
+3.3V: R47.2, R56.2; also elsewhere on the board
+24V: Q8.3 (D), Q9.3 (D), U6.12 (VBAT), U7.12 (VBAT); also elsewhere on the board
/Leg Lift Motors/M3CS: C32.2, R53.2; also elsewhere on the board
/Leg Lift Motors/M3ENA/B: R49.2; also elsewhere on the board
/Leg Lift Motors/M3INA: R50.2; also elsewhere on the board
/Leg Lift Motors/M3INB: R51.2; also elsewhere on the board
/Leg Lift Motors/M3OUTA: D18.2, D19.1, J16.2, U6.1 (OUTA), U6.25 (OUTA__1), U6.30 (OUTA__2), U6.HS2 (OUTA__3)
/Leg Lift Motors/M3OUTB: J16.1, R46.2, U6.15 (OUTB), U6.16 (OUTB__1), U6.21 (OUTB__2), U6.HS3 (OUTB__3)
/Leg Lift Motors/M3PWM: R52.2, R54.2; also elsewhere on the board
/Leg Lift Motors/M4CS: C35.2, R62.2; also elsewhere on the board
/Leg Lift Motors/M4ENA/B: R58.2; also elsewhere on the board
/Leg Lift Motors/M4INA: R59.2; also elsewhere on the board
/Leg Lift Motors/M4INB: R60.2; also elsewhere on the board
/Leg Lift Motors/M4OUTA: D20.2, D21.1, J17.2, U7.1 (OUTA), U7.25 (OUTA__1), U7.30 (OUTA__2), U7.HS2 (OUTA__3)
/Leg Lift Motors/M4OUTB: J17.1, R55.2, U7.15 (OUTB), U7.16 (OUTB__1), U7.21 (OUTB__2), U7.HS3 (OUTB__3)
/Leg Lift Motors/M4PWM: R61.2, R63.2; also elsewhere on the board
/Leg Lift Motors/VMOT3: C30.2, C31.1, Q8.2 (S), U6.3 (VCC), U6.13 (VCC__1), U6.23 (VCC__2), U6.HS1 (VCC__3)
/Leg Lift Motors/VMOT4: C33.2, C34.1, Q9.2 (S), U7.3 (VCC), U7.13 (VCC__1), U7.23 (VCC__2), U7.HS1 (VCC__3)
unnamed: D18.1, D19.2, R46.1
unnamed: D20.1, D21.2, R55.1
unnamed: Q8.1 (G), U6.11 (CP)
unnamed: Q9.1 (G), U7.11 (CP)
unnamed: R48.2, R53.1, U6.8 (CS)
unnamed: R47.1, R49.1, U6.5 (ENA/DIAGA), U6.9 (ENB/DIAGB)
unnamed: R50.1, U6.4 (INA)
unnamed: R51.1, U6.10 (INB)
unnamed: R52.1, U6.7 (PWM)
unnamed: R57.2, R62.1, U7.8 (CS)
unnamed: R56.1, R58.1, U7.5 (ENA/DIAGA), U7.9 (ENB/DIAGB)
unnamed: R59.1, U7.4 (INA)
unnamed: R60.1, U7.10 (INB)
unnamed: R61.1, U7.7 (PWM)

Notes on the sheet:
Motor H-Bridges

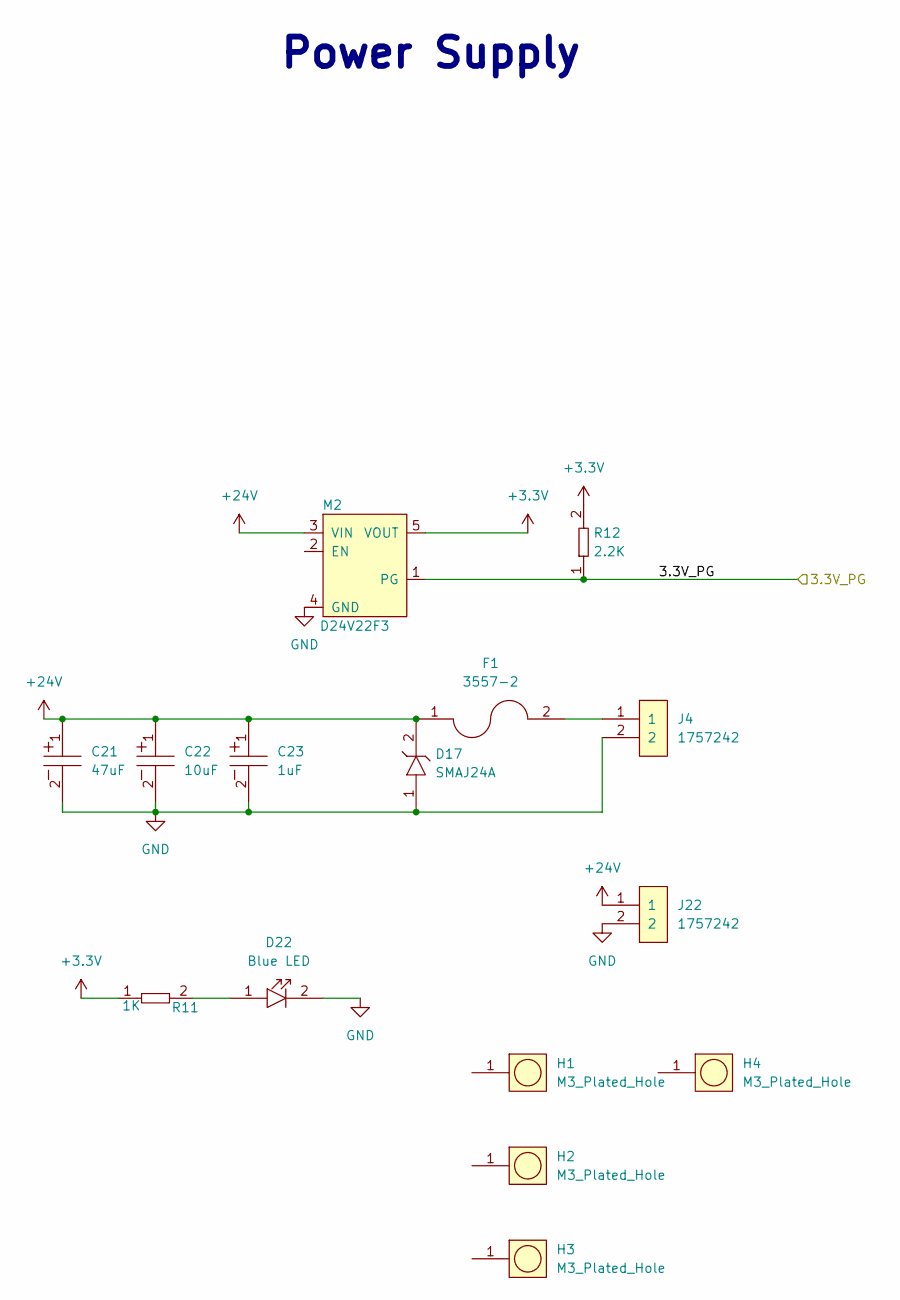
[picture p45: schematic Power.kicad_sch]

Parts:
C21: UUQ1H470MCL1GS; CP_Elec_8x10; Tolerance 20%; Voltage 50V; MFR# UUQ1H470MCL1GS
C22: UUQ1H100MCL1GB; CP_Elec_4x5.3; Tolerance 20%; Voltage 50V; MFR# UUQ1H100MCL1GB
C23: UUQ1H010MCL1GB; CP_Elec_4x5.3; Tolerance 20%; Voltage 50V; MFR# UUQ1H010MCL1GB
D17: SMAJ24A; SMAJ; Tolerance *; Voltage 24V RS, 26.7V VB, 38.9V Clamp; MFR# SMAJ24A
D22: LTST-C194TBKT; LED0603; Tolerance *; Voltage 3.3V; MFR# LTST-C194TBKT
F1: 3557-2; FUSE_3557-2; Tolerance *; Voltage 500V; MFR# 3557-2
H1, H2, H3, H4: M3_Plated_Hole; M3_HOLE; Tolerance *; Voltage *; MFR# *
J4, J22: 1757242; PhoenixContact_MSTBA-G_02x5.08mm_Angled; Tolerance *; Voltage 300V; MFR# 1757242
M2: D24V22F3; D24V22F12; Tolerance N/A; Voltage 36V IN 3.3V OUT; MFR# D24V22F3
R11: RC0402FR-071KL; R0402; Tolerance 1%; Voltage *; MFR# RC0402FR-071KL
R12: RC0603FR-072K2L; R0603; Tolerance 1%; Voltage N/A; MFR# RC0603FR-072K2L

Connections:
+3.3V: M2.5 (VOUT), R11.1, R12.2; also elsewhere on the board
+24V: C21.1, C22.1, C23.1, D17.2, F1.1, J22.1, M2.3 (VIN); also elsewhere on the board
/Power/3.3V_PG: M2.1 (PG), R12.1; also elsewhere on the board
unnamed: D22.1, R11.2
unnamed: F1.2, J4.1

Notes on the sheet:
Power Supply


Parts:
C24, C25: UUQ1H470MCL1GS; CP_Elec_8x10; Tolerance 20%; Voltage 50V; MFR# UUQ1H470MCL1GS
C26, C27: CL21B104KBFNNNE; C0805; Tolerance 10%; Voltage 50V; MFR# Samsung Electro-Mechanics
C28, C29: C0402C333K4REC7867; C0402; Tolerance 10%; Voltage 16V; MFR# C0402C333K4REC7867
D13, D15: LTST-C194KGKT; LED0603; Tolerance *; Voltage 2.1V; MFR# LTST-C194KGKT
D14, D16: LTST-C194TBKT; LED0603; Tolerance *; Voltage 3.3V; MFR# LTST-C194TBKT
J5, J6: 1757242; PhoenixContact_MSTBA-G_02x5.08mm_Angled; Tolerance *; Voltage 300V; MFR# 1757242
Q6, Q7: BSC014N04LSIATMA1; PG-TDSON-8_INF; Tolerance N/A; Voltage 40V; MFR# BSC014N04LSIATMA1
R28, R29: RC0805FR-074K7L; R0805; Tolerance 1%; Voltage *; MFR# RC0805FR-074K7L
R30, R32, R33, R34, R35, R36, R37, R38, R39, R40: RC0402FR-071KL; R0402; Tolerance 1%; Voltage *; MFR# RC0402FR-071KL
R31, R41, R42, R43: RC0402FR-0710KL; R0402; Tolerance 1%; Voltage *; MFR# RC0402FR-0710KL
R44, R45: RC0402FR-074K7L; R0402; Tolerance 1%; Voltage *; MFR# RC0402FR-074K7L
U4, U5: VNH5019ATR-E; IC_VNH5019ATR-E; Tolerance *; Voltage 24; MFR# VNH5019ATR-E

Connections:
+3.3V: R44.2, R45.2; also elsewhere on the board
+24V: Q6.3 (D), Q7.3 (D), U4.12 (VBAT), U5.12 (VBAT); also elsewhere on the board
/Motor H-Bridges/M1CS: C28.2, R31.2; also elsewhere on the board
/Motor H-Bridges/M1ENA/B: R30.2; also elsewhere on the board
/Motor H-Bridges/M1INA: R32.2; also elsewhere on the board
/Motor H-Bridges/M1INB: R33.2; also elsewhere on the board
/Motor H-Bridges/M1OUTA: D13.2, D14.1, J5.2, U4.1 (OUTA), U4.25 (OUTA__1), U4.30 (OUTA__2), U4.HS2 (OUTA__3)
/Motor H-Bridges/M1OUTB: J5.1, R28.2, U4.15 (OUTB), U4.16 (OUTB__1), U4.21 (OUTB__2), U4.HS3 (OUTB__3)
/Motor H-Bridges/M1PWM: R34.2, R42.2; also elsewhere on the board
/Motor H-Bridges/M2CS: C29.2, R41.2; also elsewhere on the board
/Motor H-Bridges/M2ENA/B: R35.2; also elsewhere on the board
/Motor H-Bridges/M2INA: R36.2; also elsewhere on the board
/Motor H-Bridges/M2INB: R37.2; also elsewhere on the board
/Motor H-Bridges/M2OUTA: D15.2, D16.1, J6.2, U5.1 (OUTA), U5.25 (OUTA__1), U5.30 (OUTA__2), U5.HS2 (OUTA__3)
/Motor H-Bridges/M2OUTB: J6.1, R29.2, U5.15 (OUTB), U5.16 (OUTB__1), U5.21 (OUTB__2), U5.HS3 (OUTB__3)
/Motor H-Bridges/M2PWM: R38.2, R43.2; also elsewhere on the board
/Motor H-Bridges/VMOT1: C24.1, C26.2, Q6.2 (S), U4.3 (VCC), U4.13 (VCC__1), U4.23 (VCC__2), U4.HS1 (VCC__3)
/Motor H-Bridges/VMOT2: C25.1, C27.2, Q7.2 (S), U5.3 (VCC), U5.13 (VCC__1), U5.23 (VCC__2), U5.HS1 (VCC__3)
unnamed: D13.1, D14.2, R28.1
unnamed: D15.1, D16.2, R29.1
unnamed: Q6.1 (G), U4.11 (CP)
unnamed: Q7.1 (G), U5.11 (CP)
unnamed: R31.1, R39.2, U4.8 (CS)
unnamed: R30.1, R44.1, U4.5 (ENA/DIAGA), U4.9 (ENB/DIAGB)
unnamed: R32.1, U4.4 (INA)
unnamed: R33.1, U4.10 (INB)
unnamed: R34.1, U4.7 (PWM)
unnamed: R40.2, R41.1, U5.8 (CS)
unnamed: R35.1, R45.1, U5.5 (ENA/DIAGA), U5.9 (ENB/DIAGB)
unnamed: R36.1, U5.4 (INA)
unnamed: R37.1, U5.10 (INB)
unnamed: R38.1, U5.7 (PWM)

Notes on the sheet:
Motor H-Bridges

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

Board: 4 copper layers, 140.0 x 100.0 mm, 181 parts (0 on the bottom side), 140 nets.

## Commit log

2024-07-12 Projects Created and Schematics Started
    Devised a complete architecture for chair recline system controls after consulting with Matt Lacey. System split across two boards. One board will function as controller, interfacing with switches/7S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
    [Display.kicad_sch, EndStops.kicad_sch, H-Bridges.kicad_sch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]
2024-07-15 Recline Actuator Control
    Recline controller board schematic and Recline actuator board schematics. Actuator control board schematic 90% complete.
    [EndStops.kicad_sch, H-Bridges.kicad_sch, MOSFETS.kicad_sch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]
2024-07-15 Actuator Control Schematic
    Schematic for Actuator control board completed! Once reviewed PCB layout will start.
    [EndStops.kicad_sch, RP2040.kicad_sch]
2024-07-15 Recline Controls
    Recline Control board and human machine interface board schematic complete !
    [Display.kicad_sch, RP2040.kicad_sch, Switches.kicad_sch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]
2024-07-15 7 Segment Carrier
    Created project and schematic for 7 segment display carrier board. It needs to be mounted at a right angle and there are no right angle 7 segment displays on the market so it will be mounted to a car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
    [7Segment-carrier.kicad_pcb, 7Segment-carrier.kicad_sch]
2024-07-16 Read Me
    Updated readme with description of boards and their function with block diagram.
2024-07-22 PCB Started
    PCB design for Recline Control Board started, figuring out PCB shape and connector positioning, work in progress !
    [Display.kicad_sch, RP2040.kicad_sch, Recline_Control_Board_1590BBBK_Shape.dxf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]
2024-07-22 Recline Actuator Control PCB
    Recline Actuator Control PCB created. Still need to figure out board shape and connector placement.
    [RP2040.kicad_sch, recline-actuator-controller.kicad_pcb]
2024-07-23 Connectors
    Datasheet for IP67 connectors added
2024-07-24 Actuator Control Board MOSFET
    Swapped Actuator control board MOSFET over to a more thermally efficient part
    [H-Bridges.kicad_sch, MOSFETS.kicad_sch, recline-actuator-controller.kicad_pcb]
2024-08-03 Switching Workstations
    Syncing progress for switching to mobile workstation
    [recline-actuator-controller.kicad_pcb]
2024-09-24 PCB shape and Layout
    PCB shape defined, parts placed 90% layout in progress.
    [Actator_Board_Shape.dxf, recline-actuator-controller.kicad_pcb]
2024-09-24 PCB Layout Progress
    Lots of progress made on PCB layout, MOSFET section complete, H-Bridges in progress, lots of work done and lots more to do, 3 copper layers are being utilized to provide ample copper for carrying all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
    [Power.kicad_sch, recline-actuator-controller.kicad_pcb]
2024-09-30 Actuator Control Board - RP2040
    RP2040 section routed on Actuator control board !
    [recline-actuator-controller.kicad_pcb]
2024-10-05 First Pass of PCB
    First pass of PCB complete, needs review.
    [RP2040.kicad_sch, recline-actuator-controller.kicad_pcb]
2024-11-02 All Hardware Tweaked / 3D Renders
    PCBs for Actuator Control, Recline Control HID, and 7 Segment carrier are all complete with full 3D models rendering. 3D Renders of all board added to repository img directory.
    [7Segment-carrier.kicad_pcb, 7Segment-carrier.kicad_sch, Display.kicad_sch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]
2024-11-02 Update README.md
    First update to read me ! Added 3D renders for both boards, reorganized order of read me images and text.
2024-11-02 Update README.md
    Recline actuator controller board description updated
2024-11-02 Update README.md
    Recline Control Board descirption updated
2024-11-02 ISO and 2D Renders
    ISO 3D renders of Actuator board
2024-11-02 Update README.md
    Added 2D renders of boards
2024-11-02 Update README.md
    Added ISO 3D renders of actuator controller board, and tweaked specs for both boards to reflect new features.
2024-11-06 More Motor Channels
    Adding more motor channels to actuator control board it will need new MCU or port expansion.
    [EndStops.kicad_sch, Leg_Lift_H_Bridges.kicad_sch, recline-actuator-controller.kicad_pcb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]
2024-12-17 Recline Actuator Board Redesign
    Recline actuator control board redesign complete, functionality extended to handle two additional large actuators for leg lifting. Air compressor switching circuit made to handle higher current. Additional end stops for additional actuators added, IO expander added for more input to RP2040. Current sensing for all 4 actuators.
    [EndStops.kicad_sch, IO_Expander.kicad_sch, Power.kicad_sch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]
2024-12-18 RS485
    RS485 schematic corrected, 5V regulator removed.
    [Power.kicad_sch, RS485.kicad_sch, recline-actuator-controller.kicad_pcb]
2024-12-21 RS485
    RS485 circuit fixed and PCB topology updated.
    [RS485.kicad_sch, recline-actuator-controller.kicad_pcb]
2024-12-28 Via Stichign and Pullups
    Added optional pullups to endstop circuit. Revised via stitching for input power, revised layout with added via stitching and copper pours for solenoid mosfets.
    [EndStops.kicad_sch, Power.kicad_sch, recline-actuator-controller.kicad_pcb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]
2024-12-30 HID
    Changes made to recline control HID board. Power input section redesigned, 5V regulator removed, RS485 circuit updated with fixes that other boards received. Redesign or internal plane topology following changes to RS485 section. Via stitching all around.
    [Power.kicad_sch, RP2040.kicad_sch, RS485.kicad_sch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]
2024-12-31 Powerplane
    Recline actuator controller power plane topology modified and upgraded
    [recline-actuator-controller.kicad_pcb]
2025-01-09 3D Models
    3D Models of circuit boards generated and added to project.
    [recline-actuator-controller.kicad_pcb, recline-controls.kicad_pcb]
2025-01-10 Board Pinout Tables
    Pinout charts for RP2040 Pin connections and signal functions added to main repo directory.
    [Recline Actuator RP2040 Pinout .ods, Recline Control HID RP2040 Pinout.ods]
2025-01-13 PDF Schematics
    PDFs of schematics added for firmware developers
2025-03-11 Silkscreen
    Bottom Silkscreen edits.
    [recline-actuator-controller.kicad_pcb, recline-controls.kicad_pcb]
